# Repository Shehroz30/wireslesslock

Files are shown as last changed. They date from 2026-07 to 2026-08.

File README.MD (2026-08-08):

# Wireless bike lock

An ESP32-S3 hosts a web page over WiFi; the Open control energizes a latching solenoid in a
padlock body. The page also reports accelerometer and GPS readings.

The design covers two parts: the control PCB and the padlock. The rest is an existing bike
lock frame.

## How it works

An ESP32-S3 hosts a web page over WiFi; the Open control energizes a latching solenoid in a
padlock body. The page also reports accelerometer and GPS readings.

Interconnect sheet (parts, wiring diagram, wire schedule, open items):

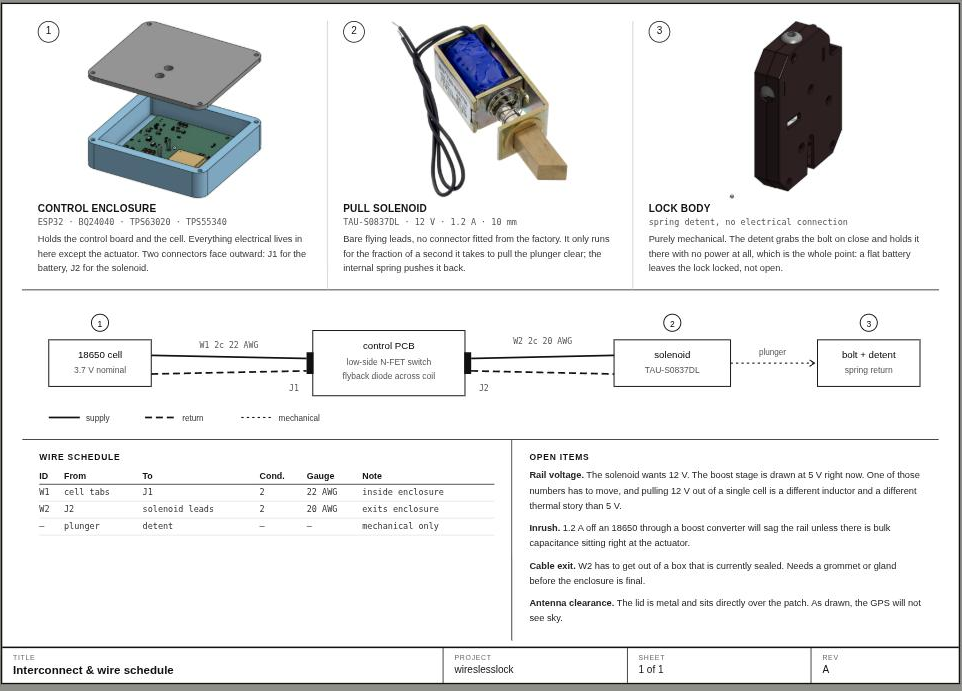
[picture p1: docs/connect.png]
Interconnect & wire schedule


Source (styled, printable): [connect.html](connect.html)

Mechanical design (enclosure and padlock body) is in Onshape:
<https://cad.onshape.com/documents/6c2c18833c9d8444570c43c7/w/6a4bb112d0b0db7159f785b0/e/d206a90808809049c3ae2997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>

PCB in enclosure:
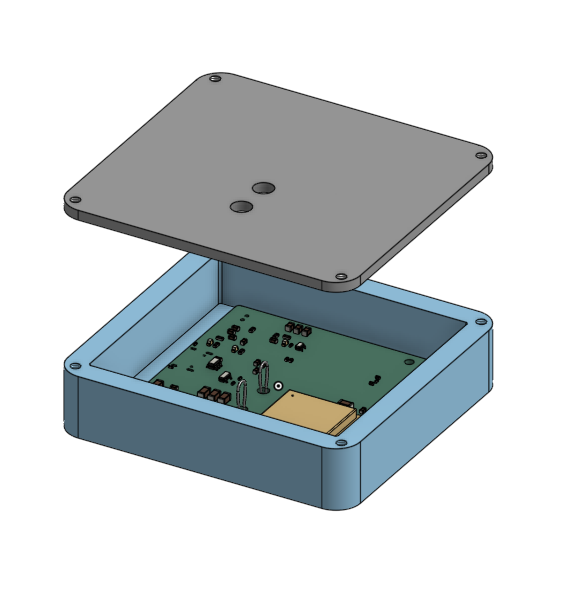
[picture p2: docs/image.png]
PCB in enclosure


Padlock with latching solenoid:
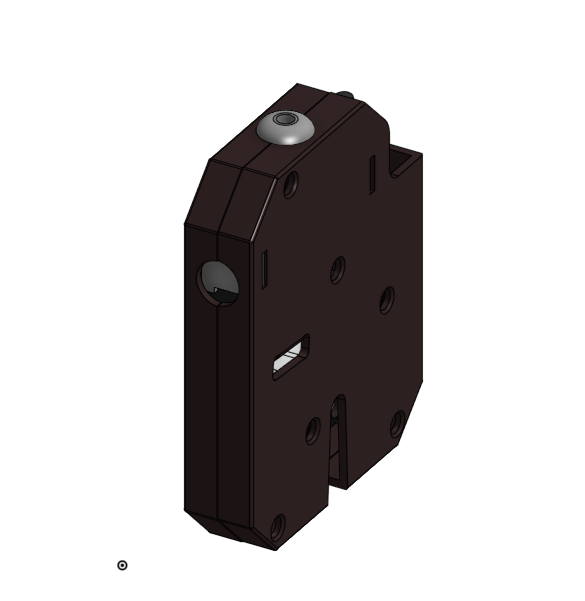
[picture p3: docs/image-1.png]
padlock


## Board specification

| | |
|---|---|
| Dimensions | 50 × 50 mm |
| Stackup | 4 layer (F.Cu / In1.Cu / In2.Cu / B.Cu), 1.6 mm |
| MCU | ESP32-S3-WROOM-1 (WiFi + BLE) |
| Power in | USB-C 5 V, single-cell Li-ion via JST-PH |
| Rails | 3.3 V system (buck-boost), 12 V solenoid (boost) |
| Sensors | LIS2DH12 accelerometer (SPI), SIM68M GNSS + SMD antenna (UART) |
| EDA | KiCad 10.0 |
| Placements | 67 across 44 BOM lines |

## Circuit description

### Power tree

```
USB-C (J1, 5V) ──> U1 BQ24040 ──> Li-ion cell (J2)
                   charge mgmt         │
                                       ├──> U3 TPS63020 buck-boost ──> +3.3V  (MCU, GPS, accel)
                                       │                                 │
                                       └── R7 10k pullup -> U3 EN        └──> U4 TPS55340 boost ──> +12V (solenoid)
```

`U1` (BQ24040) takes 5 V from USB-C and charges the cell. `R1` (560 Ω on ISET) sets the
fast-charge current; `D1`/`D2` are its status outputs. `R2`/`R3` are the 5.1 k CC pulldowns
that make a USB-C source supply 5 V, and `U2` (USBLC6-2SC6) clamps ESD on D+/D−.

The 3.3 V rail comes from `U3` (TPS63020), a buck-boost. A Li-ion cell sags from 4.2 V past
3.3 V as it discharges, so a buck-only regulator would brown out the ESP32 before the cell
was empty. Output is set by `R9` (1 M) / `R10` (180 k) around the 0.5 V reference → 3.28 V.
Inductor is `L2` (2.2 µH).

`U4` (TPS55340) boosts 3.3 V to 12 V through `L1` (10 µH) and `D3`, set by `R12` (86.6 k) /
`R13` (10 k) around the 1.229 V reference → ≈11.9 V. It is a separate rail so solenoid inrush
draws from the bulk caps (`C12`/`C14`/`C16`) rather than the MCU supply.

### Solenoid drive

`CTRL_P` (GPIO40) → `R18` (220 Ω gate series) → `Q1` (AO3400A, low-side N-ch FET). `R17`
(10 k) pulls the gate down so the coil is off through boot and reset. `D4` (S1M) is the
flyback diode across the coil. The coil connects to `TP1` (+12 V) and `TP2` (Q1 drain).

There is no hold-current limiting in hardware. The firmware caps coil energization time
instead (`MAX_OPEN_MS`, 5 s). Any other code driving `CTRL_P` must enforce the same limit.

### GPS

`U6` (SIM68M) streams NMEA at 9600 baud on the primary UART. `U8` (GPS1003) is the SMD
antenna, fed through a pi matching network: shunt `C22`, series `R19` (0 Ω), shunt `L4`
(18 nH). The 0 Ω / 0402 placeholders allow the match to be tuned after measurement.

## Pin map (U5, ESP32-S3-WROOM-1)

| Net | GPIO | Connects to |
|---|---|---|
| `CTRL_P` | 40 | Q1 gate (solenoid) via R18 |
| `LI_CS` | 10 | LIS2DH12 chip select |
| `SPI_MOSI` | 11 | LIS2DH12 SDI |
| `SPI_SCK` | 12 | LIS2DH12 SPC |
| `SPI_MISO` | 13 | LIS2DH12 SDO |
| `UART1_RX` | 17 | SIM68M TXD0, primary NMEA out |
| `UART1_TX` | 18 | SIM68M RXD0 |
| `UART0_RX` / `UART0_TX` | 6 / 7 | SIM68M secondary/debug UART |
| `BOOT` | 0 | SW3 tactile |
| `RST` | EN | SW2 tactile (R16 10 k pullup) |
| `TM` | — | Q2 → status LED D5; unused by the current firmware |

The accelerometer runs SPI mode 3 at 1 MHz. Its INT1/INT2 pins are not connected, so motion
detection is by polling.

## Firmware

The sketch is `firmware/wireslesslock_controller/wireslesslock_controller.ino`. It joins a
WiFi network, serves a page on port 80, and polls `/data` once a second for accelerometer and
GPS values. There is no cloud service or backend; the lock is reachable only on the local
network.

| Route | Method | Function |
|---|---|---|
| `/` | GET | Control page |
| `/data` | GET | JSON: `locked`, `accel.x/y/z` (g), `gps.fix/sats/lat/lon` |
| `/open` | POST | Energize solenoid (auto-releases after 5 s) |
| `/close` | POST | De-energize |

### Flashing

1. Arduino IDE → Boards Manager → install the esp32 package.
2. Library Manager → install TinyGPSPlus (Mikal Hart). The remaining dependencies are part of
   the ESP32 core.
3. Set `WIFI_SSID` / `WIFI_PASS` at the top of the sketch.
4. Connect over USB, select the board and port under Tools, and upload.

If upload stalls at `Connecting...`: hold BOOT (SW3), tap RESET (SW2), release BOOT. After
"Done uploading" the sketch is running; the serial monitor at 115200 baud prints the assigned
IP address.

## Fabrication

`gerbers.zip` is the fab package: 4 layer, 1.6 mm, 50 × 50 mm.

For assembly, `production/` holds `bom.csv`, `positions.csv`, `designators.csv`, and
`netlist.ipc`. These are generated by the KiCad Fabrication Toolkit plugin (settings in
`fabrication-toolkit-options.json`); regenerate them with the plugin rather than editing the
CSVs directly.

All parts are LCSC/JLCPCB-orderable except the solenoid and the battery, which are selected to
fit the padlock body.

## Bill of materials

67 placements, 44 lines. Machine-readable copy with purchase links: [BOM.csv](BOM.csv).
`production/bom.csv` is the plugin-generated file and is the reference for designators and
values; the table below adds the function of each part.

| Designator | Qty | Value | Footprint | Function | LCSC |
|---|---|---|---|---|---|
| `C1, C2` | 2 | 1uf | 0603 | USB VBUS / charger input bulk decoupling (U1 BQ24040 IN, OUT) | [C15849](https://www.lcsc.com/search?q=C15849) |
| `C10` | 1 | 100nF | 0402 | ESP32-S3 (U5) supply decoupling | [C1525](https://www.lcsc.com/search?q=C1525) |
| `C11, C19, C21, C7` | 4 | 0.1uF | 0603 | General IC decoupling (U4 VIN/VCC, GPS, accel) | [C14663](https://www.lcsc.com/search?q=C14663) |
| `C12, C14, C16, C5` | 4 | 4.7uF | 1206 | 12V solenoid rail bulk output caps (U4 boost output) | [C29823](https://www.lcsc.com/search?q=C29823) |
| `C13, C15, C17` | 3 | 22uf | 0805 | 3.3V rail bulk output caps (U3 buck-boost output) | [C45783](https://www.lcsc.com/search?q=C45783) |
| `C18, C26, C27, C3, C8` | 5 | 100nF | 0603 | Local HF decoupling, 3.3V rail | [C14663](https://www.lcsc.com/search?q=C14663) |
| `C20` | 1 | 22uF | 1206 | 3.3V bulk reservoir for RF/GPS current bursts | [C12891](https://www.lcsc.com/search?q=C12891) |
| `C22, R19` | 2 | 0 | 0402 | GPS antenna pi-match: shunt cap + series 0R (U8 -> U6 GNSS_ANT) | [C1952](https://www.lcsc.com/search?q=C1952) |
| `C23` | 1 | 4.7uF | 0402 | 3.3V decoupling, SIM68M GPS module (U6) | [C23733](https://www.lcsc.com/search?q=C23733) |
| `C28, C4, C6` | 3 | 10uF | 0603 | Mid-value decoupling, battery and 3.3V rails | [C19702](https://www.lcsc.com/search?q=C19702) |
| `C9` | 1 | 0.047uF | 0603 | TPS55340 (U4) soft-start cap on SS pin | [C1622](https://www.lcsc.com/search?q=C1622) |
| `D1, D2, D5` | 3 | LED | 0603 | Status LEDs: D1/D2 = BQ24040 CHG/PGOOD, D5 = MCU-driven (via Q2) | [C2290](https://www.lcsc.com/search?q=C2290) |
| `D3` | 1 | D_Schottky | SMA_L4.3-W2.7-LS5.1-RD | Boost rectifier for U4 (SW node -> +12V) | [C8678](https://www.lcsc.com/search?q=C8678) |
| `D4` | 1 | S1M | SMA_L4.3-W2.7-LS5.1-RD | Flyback/freewheel diode across the solenoid coil | [C51898151](https://www.lcsc.com/search?q=C51898151) |
| `J1` | 1 | MC-311D | USB-C-SMD_MC-311D | USB-C receptacle: 5V charge input + native USB D+/D- | [C136423](https://www.lcsc.com/search?q=C136423) |
| `J2` | 1 | BATTERY | CONN-TH_S2B-PH-K-S-GW | JST-PH 2-pin Li-ion battery connector | [C157932](https://www.lcsc.com/search?q=C157932) |
| `L1` | 1 | 10uH | IND-SMD_L7.2-W6.6_GPSR07X0 | 10uH boost inductor for U4 (+3.3V -> +12V) | [C5189958](https://www.lcsc.com/search?q=C5189958) |
| `L2` | 1 | 2.2uH | L1008 | 2.2uH buck-boost inductor for U3 (TPS63020 L1/L2 pins) | [C86092](https://www.lcsc.com/search?q=C86092) |
| `L4` | 1 | 18nH | 0402 | 18nH shunt inductor, GPS antenna matching network | [C86060](https://www.lcsc.com/search?q=C86060) |
| `Q1` | 1 | AO3400A | SOT-23 | N-ch FET, low-side solenoid driver (gate = CTRL_P / GPIO40) | [C20917](https://www.lcsc.com/search?q=C20917) |
| `Q2` | 1 | DTC143Z | SOT-323_SC-70 | Digital NPN (built-in bias) driving status LED D5 from net TM | [C53066](https://www.lcsc.com/search?q=C53066) |
| `R1` | 1 | 560 | 0603 | BQ24040 ISET: sets fast-charge current | [C23204](https://www.lcsc.com/search?q=C23204) |
| `R10` | 1 | 180k | 0603 | U3 (TPS63020) feedback divider, bottom leg -> 3.3V out | [C22827](https://www.lcsc.com/search?q=C22827) |
| `R11` | 1 | 75k | 0603 | U4 (TPS55340) FREQ pin: switching frequency set | [C23242](https://www.lcsc.com/search?q=C23242) |
| `R12` | 1 | 86.6K | 0603 | U4 feedback divider, top leg from +12V | [C23121](https://www.lcsc.com/search?q=C23121) |
| `R13, R16, R7` | 3 | 10k | 0603 | R13 = U4 FB bottom leg (12V), R16 = RST pullup, R7 = U3 EN pullup | [C25804](https://www.lcsc.com/search?q=C25804) |
| `R17` | 1 | 10k | 0402 | Gate pulldown on CTRL_P (holds solenoid off during boot/reset) | [C60489](https://www.lcsc.com/search?q=C60489) |
| `R18` | 1 | 220 | 0402 | Gate series resistor for Q1 | [C25091](https://www.lcsc.com/search?q=C25091) |
| `R2, R3` | 2 | 5.1k | 0402 | USB-C CC1/CC2 5.1k pulldowns (advertise 5V sink) | [C25905](https://www.lcsc.com/search?q=C25905) |
| `R20` | 1 | 1k | 0402 | Series resistor for status LED D5 | [C11702](https://www.lcsc.com/search?q=C11702) |
| `R4, R5` | 2 | 1k | 0603 | Series resistors for charge-status LEDs D1/D2 | [C21190](https://www.lcsc.com/search?q=C21190) |
| `R8` | 1 | 2k | 0603 | U4 COMP network resistor (loop compensation) | [C22975](https://www.lcsc.com/search?q=C22975) |
| `R9` | 1 | 1M | 0603 | U3 feedback divider, top leg from 3.3V out | [C22935](https://www.lcsc.com/search?q=C22935) |
| `SW2, SW3` | 2 | TS-1088-AR02016 | SW-SMD_L3.9-W3.0-P4.45 | Tactile switches: SW2 = RESET (EN), SW3 = BOOT (IO0) | [C720477](https://www.lcsc.com/search?q=C720477) |
| `TP1` | 1 | VCC_SOL | TestPoint_Loop_D3.80mm_Drill2.8mm | Test point / solenoid output: +12V | — |
| `TP2` | 1 | GND_SOL | TestPoint_Loop_D3.80mm_Drill2.8mm | Test point / solenoid output: switched low side (Q1 drain) | — |
| `U1` | 1 | BQ24040DSQR | WSON-10_L2.0-W2.0-P0.40-BL-EP | Li-ion linear charge management IC (USB 5V -> battery) | [C81080](https://www.lcsc.com/search?q=C81080) |
| `U2` | 1 | USBLC6-2SC6 | SOT-23-6 | USB D+/D- ESD protection array | [C2827654](https://www.lcsc.com/search?q=C2827654) |
| `U3` | 1 | TPS63020DSJR | VSON-14_L4.0-W3.0-P0.50-BL-EP_TI_DSJ | Buck-boost converter: battery (2.5-5.5V) -> 3.3V system rail | [C15483](https://www.lcsc.com/search?q=C15483) |
| `U4` | 1 | TPS55340RTER | VQFN-16_L3.0-W3.0-P0.50-BL-EP1.7 | Boost converter: 3.3V -> 12V solenoid rail | [C169167](https://www.lcsc.com/search?q=C169167) |
| `U5` | 1 | ESP32-S3-WROOM-1 | ESP32-S3-WROOM-1 | Main MCU/radio: ESP32-S3, WiFi + BLE, hosts the control page | [C2913202](https://www.lcsc.com/search?q=C2913202) |
| `U6` | 1 | SIM68M | GPSM-SMD_18P-L10.1-W9.7-P1.10 | GNSS receiver module, NMEA out over UART at 9600 baud | [C2999762](https://www.lcsc.com/search?q=C2999762) |
| `U7` | 1 | LIS2DH12TR | LGA-12_L2.0-W2.0-P0.50-BL | 3-axis accelerometer (SPI) - tamper / motion detection | [C110926](https://www.lcsc.com/search?q=C110926) |
| `U8` | 1 | GPS1003 | ANT-SMD_L10.0-W3.0 | SMD GPS patch antenna, 1575.42 MHz | [C239243](https://www.lcsc.com/search?q=C239243) |

Not on the BOM, selected to fit the padlock:

| Item | Notes |
|---|---|
| Latching solenoid | Driven from TP1/TP2 at 12 V, low-side switched |
| Li-ion cell | Single cell, JST-PH 2-pin to J2 |

## Repository layout

```
wireslesslock.kicad_pro      project file
wireslesslock.kicad_sch      root schematic (MCU, GPS, accel, switches)
power.kicad_sch              "Power" sub-sheet (charging, both converters, USB-C)
wireslesslock.kicad_pcb      4-layer board layout
easyeda2kicad.*              project-local library: parts converted from LCSC/EasyEDA
                             (BQ24040, TPS63020, TPS55340, GPS antenna, WSON/VSON pkgs)
BOM.csv                      annotated BOM (this README's table)
production/                  generated fab outputs (plugin output, not source)
gerbers.zip                  fab package
firmware/                    ESP32-S3 Arduino sketch
3dfiles/                     STEP export + padlock mechanism snapshots from Onshape
docs/                        README images
archive/                     timestamped project backups
```

## Verifying changes

There is no build or test command. Changes are verified by opening the project in KiCad and
running ERC on the schematic and DRC on the board.

## License

[MIT](LICENSE).

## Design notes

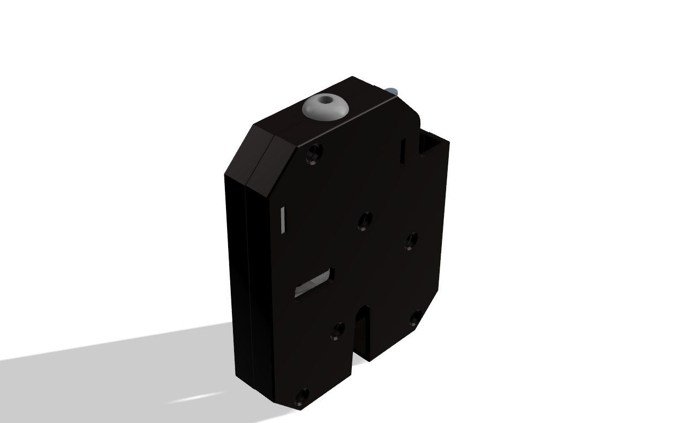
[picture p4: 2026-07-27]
3dfiles/solenoid-lock-combine-lock-1.snapshot.3/Screenshot (61).png

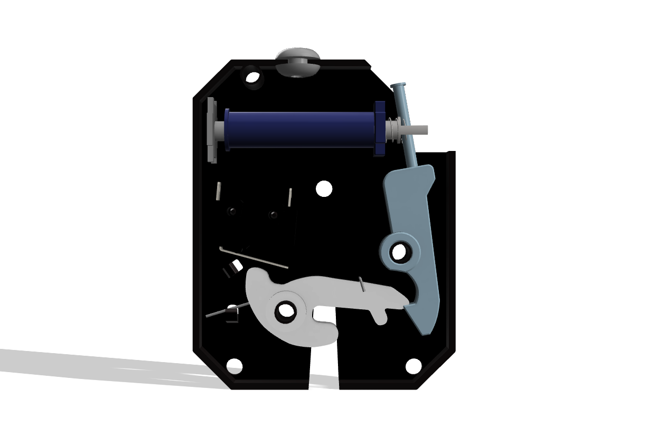
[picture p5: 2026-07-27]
3dfiles/solenoid-lock-combine-lock-1.snapshot.3/Screenshot (64).png

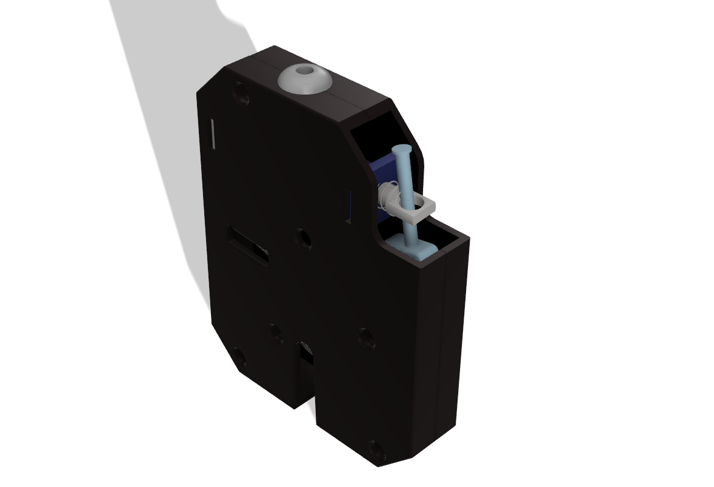
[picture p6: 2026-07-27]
3dfiles/solenoid-lock-combine-lock-1.snapshot.3/Screenshot (59).png

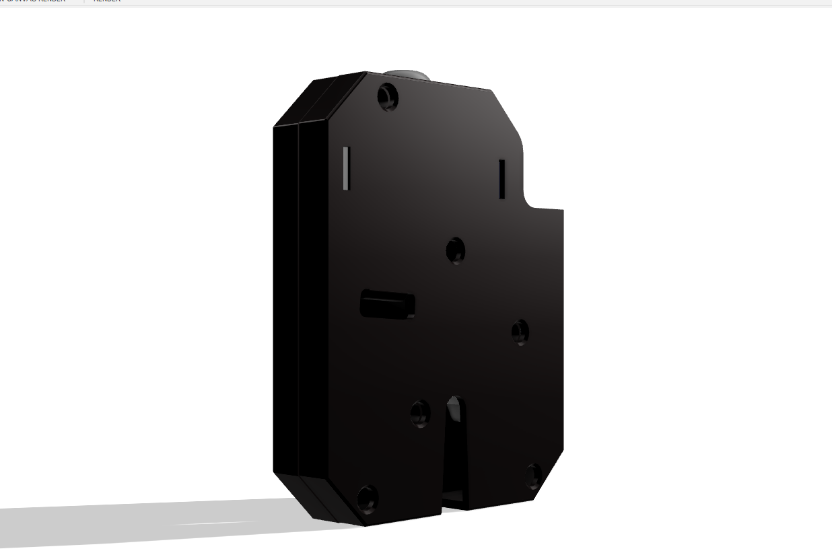
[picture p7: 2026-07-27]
3dfiles/solenoid-lock-combine-lock-1.snapshot.3/Screenshot (57).png

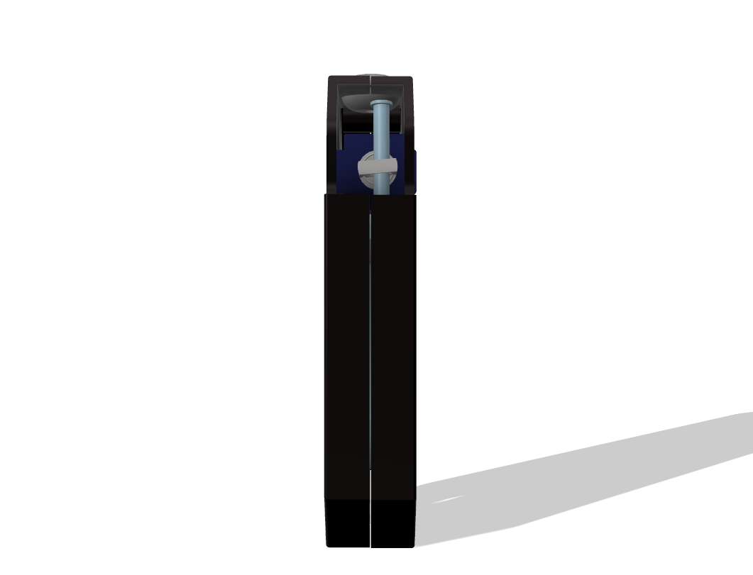
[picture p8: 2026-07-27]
3dfiles/solenoid-lock-combine-lock-1.snapshot.3/Screenshot (63).png

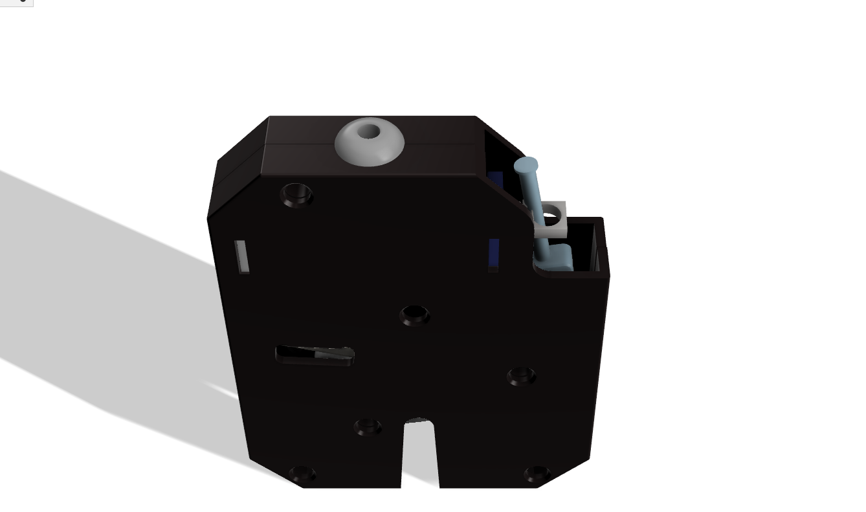
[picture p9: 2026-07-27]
3dfiles/solenoid-lock-combine-lock-1.snapshot.3/Screenshot (60).png

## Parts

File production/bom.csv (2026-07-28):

Designator | Footprint | Quantity | Value | LCSC Part #
C1, C2 | 0603 | 2 | 1uf
C10 | 0402 | 1 | 100nF
C11, C19, C21, C7 | 0603 | 4 | 0.1uF
C12, C14, C16, C5 | 1206 | 4 | 4.7uF
C13, C15, C17 | 0805 | 3 | 22uf
C18, C26, C27, C3, C8 | 0603 | 5 | 100nF
C20 | 1206 | 1 | 22uF
C22, R19 | 0402 | 2 | 0
C23 | 0402 | 1 | 4.7uF
C28, C4, C6 | 0603 | 3 | 10uF
C9 | 0603 | 1 | 0.047uF
D1, D2, D5 | 0603 | 3 | LED
D3 | SMA_L4.3-W2.7-LS5.1-RD | 1 | D_Schottky
D4 | SMA_L4.3-W2.7-LS5.1-RD | 1 | S1M
J1 | USB-C-SMD_MC-311D | 1 | MC-311D | C136423
J2 | CONN-TH_S2B-PH-K-S-GW | 1 | BATTERY
L1 | IND-SMD_L7.2-W6.6_GPSR07X0 | 1 | 10uH
L2 | L1008 | 1 | 2.2uH
L4 | 0402 | 1 | 18nH
Q1 | SOT-23 | 1 | AO3400A
Q2 | SOT-323_SC-70 | 1 | DTC143Z
R1 | 0603 | 1 | 560
R10 | 0603 | 1 | 180k
R11 | 0603 | 1 | 75k
R12 | 0603 | 1 | 86.6K
R13, R16, R7 | 0603 | 3 | 10k
R17 | 0402 | 1 | 10k
R18 | 0402 | 1 | 220
R2, R3 | 0402 | 2 | 5.1k
R20 | 0402 | 1 | 1k
R4, R5 | 0603 | 2 | 1k
R8 | 0603 | 1 | 2k
R9 | 0603 | 1 | 1M
SW2, SW3 | SW-SMD_L3.9-W3.0-P4.45 | 2 | TS-1088-AR02016 | C720477
TP1 | TestPoint_Loop_D3.80mm_Drill2.8mm | 1 | VCC_SOL
TP2 | TestPoint_Loop_D3.80mm_Drill2.8mm | 1 | GND_SOL
U1 | WSON-10_L2.0-W2.0-P0.40-BL-EP | 1 | BQ24040DSQR | C81080
U2 | SOT-23-6 | 1 | USBLC6-2SC6
U3 | VSON-14_L4.0-W3.0-P0.50-BL-EP_TI_DSJ | 1 | TPS63020DSJR | C15483
U4 | VQFN-16_L3.0-W3.0-P0.50-BL-EP1.7 | 1 | TPS55340RTER | C169167
U5 | ESP32-S3-WROOM-1 | 1 | ESP32-S3-WROOM-1
U6 | GPSM-SMD_18P-L10.1-W9.7-P1.10 | 1 | SIM68M | C2999762
U7 | LGA-12_L2.0-W2.0-P0.50-BL | 1 | LIS2DH12TR | C110926
U8 | ANT-SMD_L10.0-W3.0 | 1 | GPS1003 | C239243

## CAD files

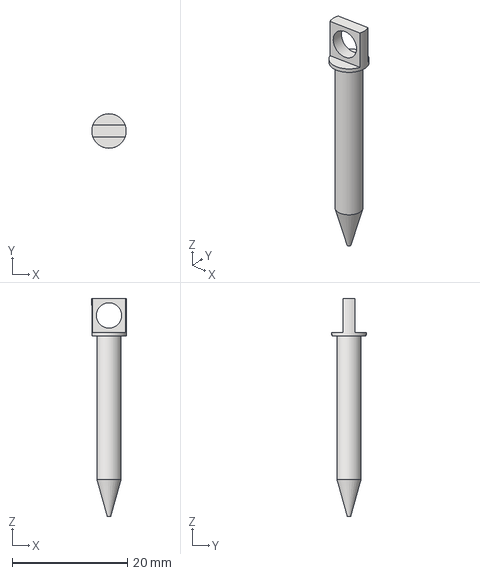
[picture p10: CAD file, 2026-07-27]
3dfiles/solenoid-lock-combine-lock-1.snapshot.3/#2 part 6 pin .step
6.00 x 6.00 x 37.9 mm

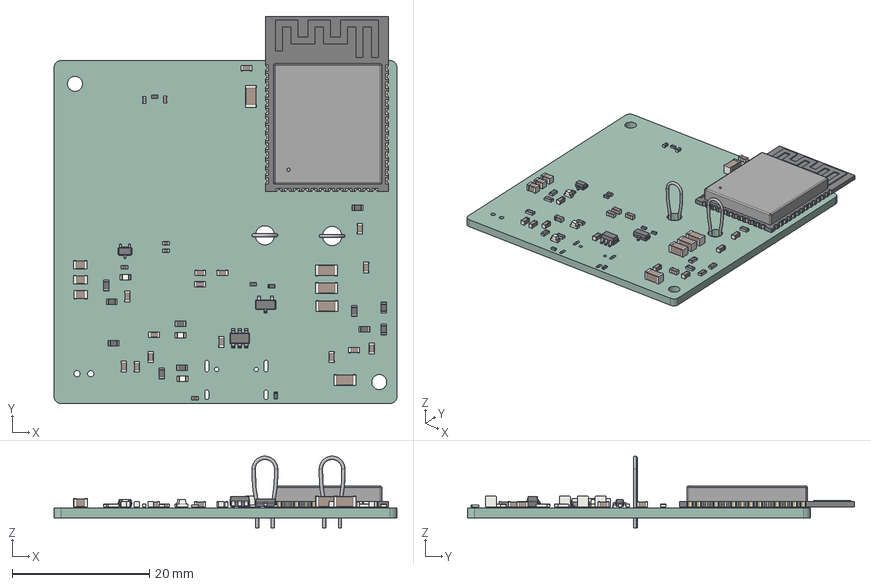
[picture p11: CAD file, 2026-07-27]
3dfiles/wireslesslock.step
50.0 x 56.4 x 10.4 mm
C_1206_3216Metric x 5
R_0402_1005Metric x 6
C_0603_1608Metric x 15
R_0603_1608Metric x 11
C_0402_1005Metric x 3
C_0805_2012Metric x 3
LED_0603_1608Metric x 3
SOT-323_SC-70
TestPoint_Loop_D3.80mm_Drill2.8mm x 2
SOT-23-6
L_0402_1005Metric
SOT-23
ESP32-S3-WROOM-1
wireslesslock_PCB

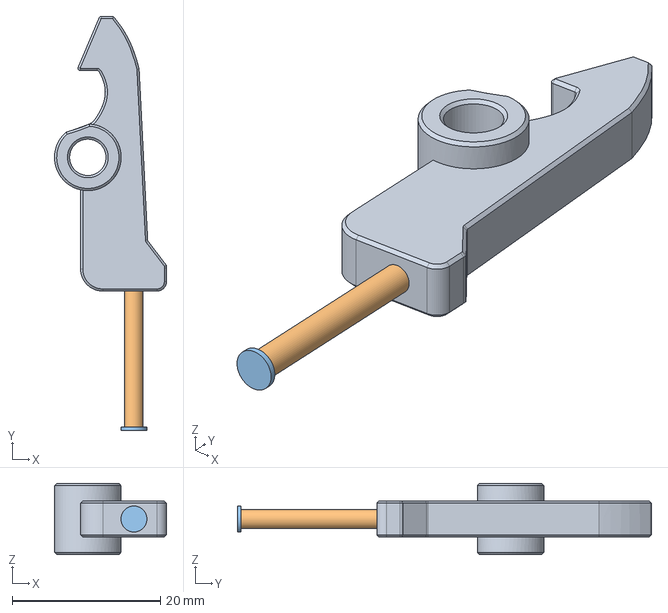
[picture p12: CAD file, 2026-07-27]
3dfiles/solenoid-lock-combine-lock-1.snapshot.3/#2 part 2 long hook .step
15.1 x 55.8 x 9.60 mm

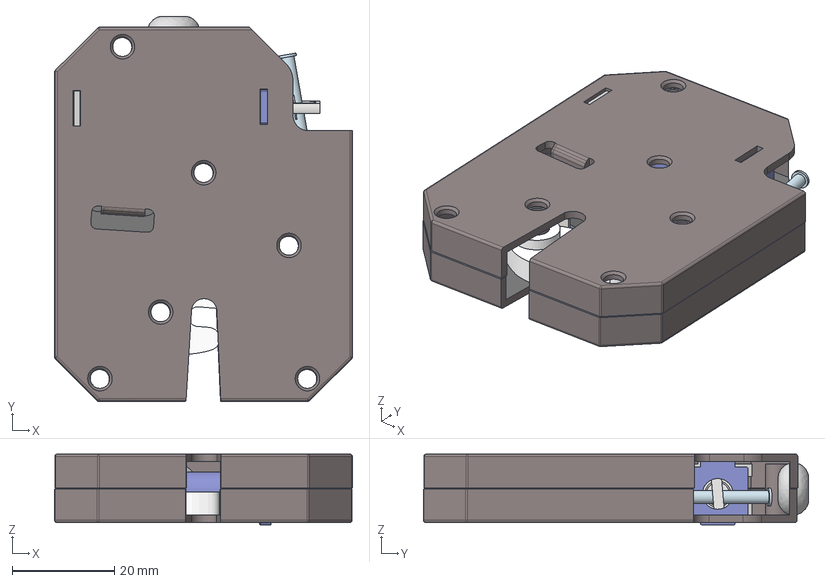
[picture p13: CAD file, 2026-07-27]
3dfiles/solenoid-lock-combine-lock-1.snapshot.3/#1 v1.step
58.2 x 75.2 x 13.9 mm
Bottom
Top

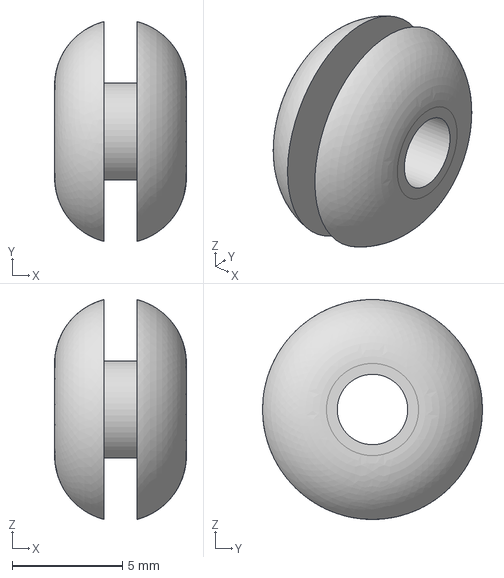
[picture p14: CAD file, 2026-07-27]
3dfiles/solenoid-lock-combine-lock-1.snapshot.3/#1 part2 .step
6.00 x 10.00 x 10.0 mm

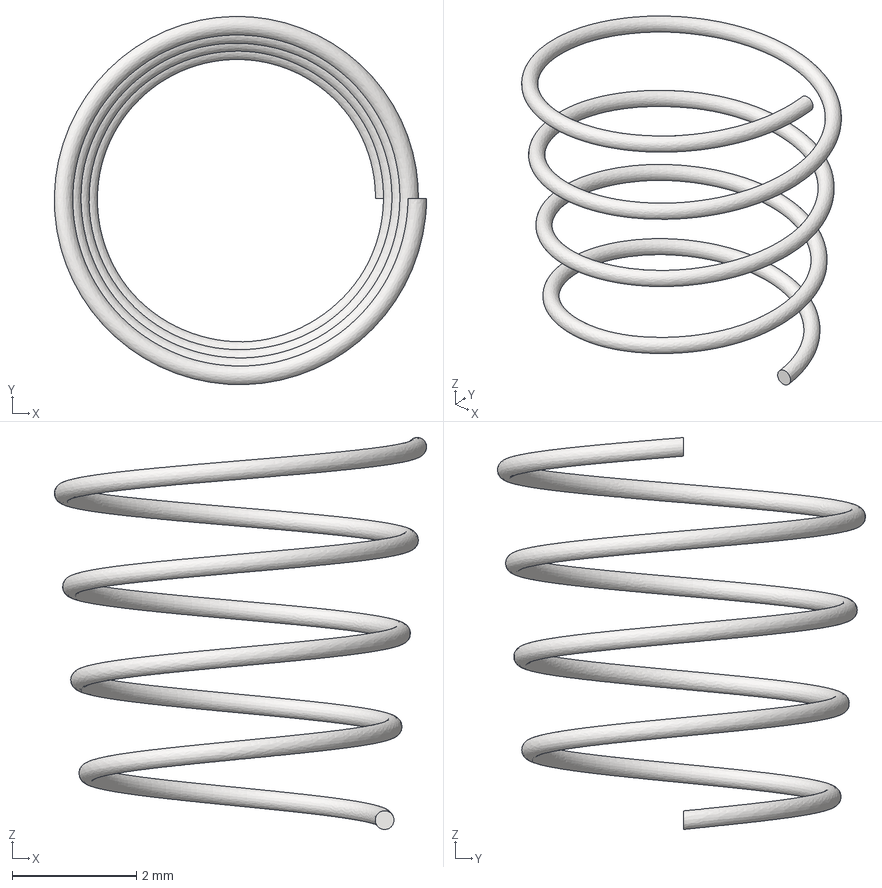
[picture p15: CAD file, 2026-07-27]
3dfiles/solenoid-lock-combine-lock-1.snapshot.3/#2 part spring .step
5.98 x 5.92 x 6.30 mm

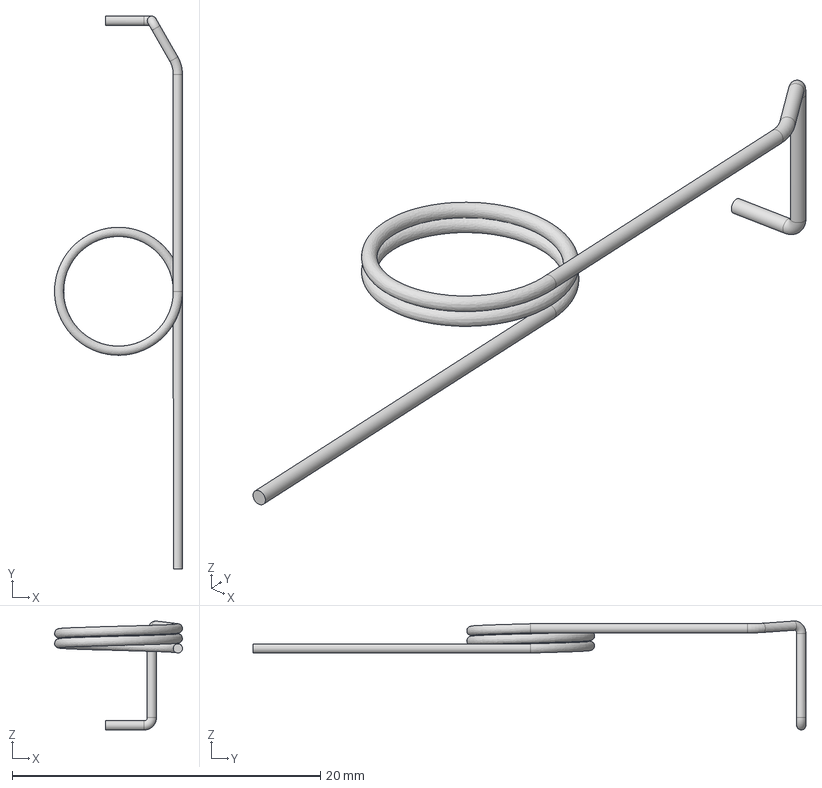
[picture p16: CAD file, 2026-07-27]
3dfiles/solenoid-lock-combine-lock-1.snapshot.3/#2 part 8 torsion spring .step
8.30 x 35.8 x 7.07 mm

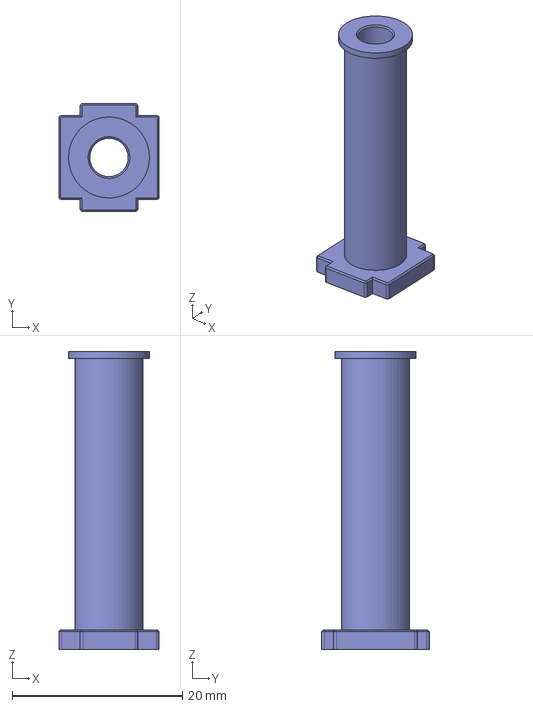
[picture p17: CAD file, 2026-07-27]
3dfiles/solenoid-lock-combine-lock-1.snapshot.3/#2 part long coil .step
11.8 x 12.7 x 35.0 mm

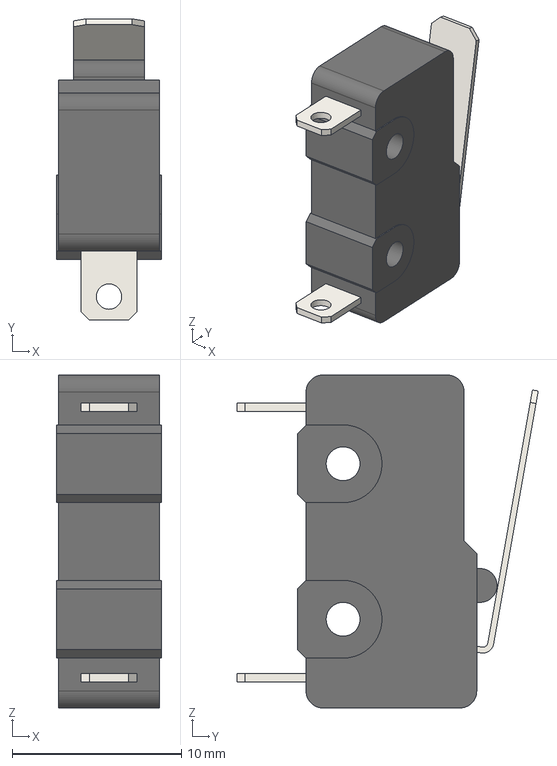
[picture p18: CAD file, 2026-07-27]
3dfiles/solenoid-lock-combine-lock-1.snapshot.3/#2 part 4 switch .step
6.20 x 17.8 x 19.7 mm

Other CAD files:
3dfiles/solenoid-lock-combine-lock-1.snapshot.3/#2 part long coil.step

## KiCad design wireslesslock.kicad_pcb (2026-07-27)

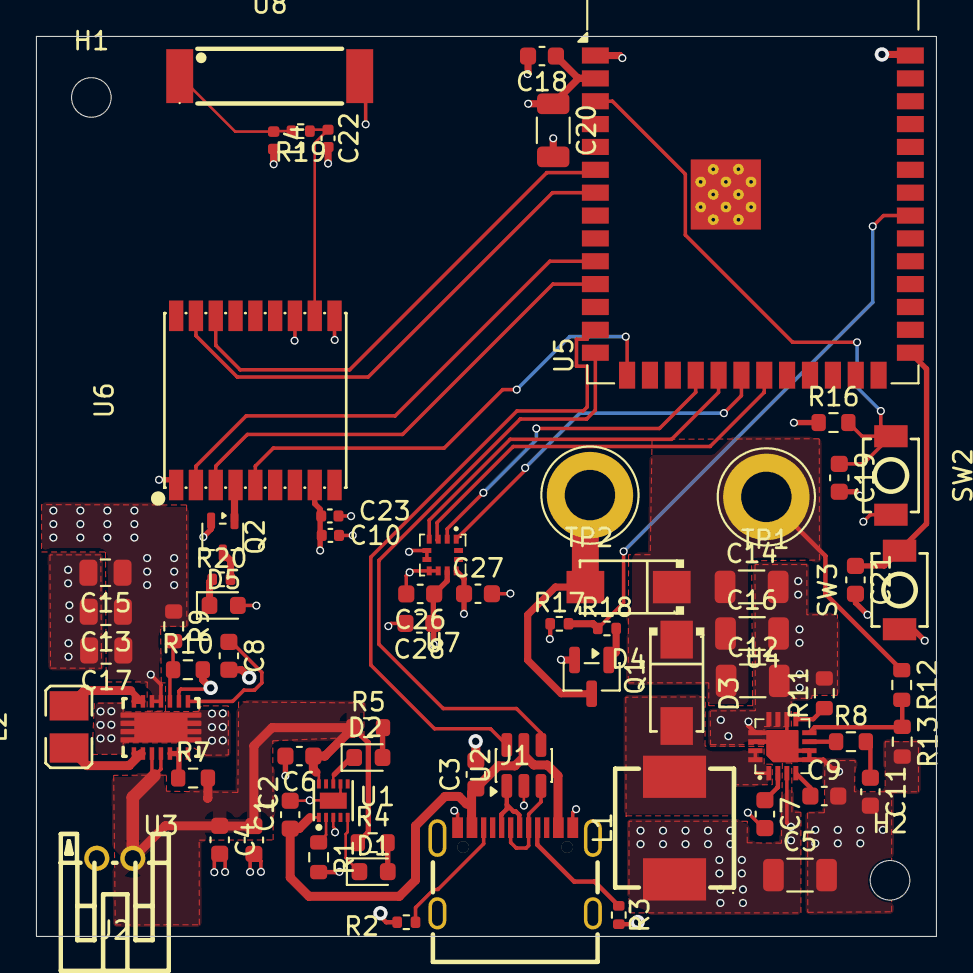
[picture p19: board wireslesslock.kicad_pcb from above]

Board: 4 copper layers, 50.0 x 50.0 mm, 69 parts (0 on the bottom side), 47 nets.

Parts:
C1, C2: 1uf; C_0603_1608Metric
C3, C18, C26, C27: 100nF; C_0603_1608Metric
C4, C6: 10uf; C_0603_1608Metric
C5, C12, C14, C16: 4.7uF; C_1206_3216Metric
C7, C11, C19, C21: 0.1uF; C_0603_1608Metric
C8: 100nf; C_0603_1608Metric
C9: 0.047uF; C_0603_1608Metric
C10: 100nF; C_0402_1005Metric
C13, C15, C17: 22uf; C_0805_2012Metric
C20: 22uF; C_1206_3216Metric
C22: 0; C_0402_1005Metric
C23: 4.7uF; C_0402_1005Metric
C28: 10uF; C_0603_1608Metric
D1, D2, D5: LED; LED_0603_1608Metric
D3: D_Schottky; SMA_L4.3-W2.7-LS5.1-RD
D4: S1M; SMA_L4.3-W2.7-LS5.1-RD
H1, H2: MountingHole; MountingHole_2.2mm_M2
J1: MC-311D; USB-C-SMD_MC-311D
J2: BATTERY; CONN-TH_S2B-PH-K-S-GW
L1: 10uH; IND-SMD_L7.2-W6.6_GPSR07X0
L2: 2.2uH; L1008
L4: 18nH; L_0402_1005Metric
Q1: AO3400A; SOT-23
Q2: DTC143Z; SOT-323_SC-70
R1: 560; R_0603_1608Metric
R2, R3: 5.1k; R_0402_1005Metric
R4, R5: 1k; R_0603_1608Metric
R7, R13, R16: 10k; R_0603_1608Metric
R8: 2k; R_0603_1608Metric
R9: 1M; R_0603_1608Metric
R10: 180k; R_0603_1608Metric
R11: 75k; R_0603_1608Metric
R12: 86.6K; R_0603_1608Metric
R17: 10k; R_0402_1005Metric
R18: 220; R_0402_1005Metric
R19: 0; R_0402_1005Metric
R20: 1k; R_0402_1005Metric
SW2, SW3: TS-1088-AR02016; SW-SMD_L3.9-W3.0-P4.45
TP1: VCC_SOL; TestPoint_Loop_D3.80mm_Drill2.8mm
TP2: GND_SOL; TestPoint_Loop_D3.80mm_Drill2.8mm
U1: BQ24040DSQR; WSON-10_L2.0-W2.0-P0.40-BL-EP
U2: USBLC6-2SC6; SOT-23-6
U3: TPS63020DSJR; VSON-14_L4.0-W3.0-P0.50-BL-EP_TI_DSJ
U4: TPS55340RTER; VQFN-16_L3.0-W3.0-P0.50-BL-EP1.7
U5: ESP32-S3-WROOM-1
U6: SIM68M; GPSM-SMD_18P-L10.1-W9.7-P1.10
U7: LIS2DH12TR; LGA-12_L2.0-W2.0-P0.50-BL
U8: GPS1003; ANT-SMD_L10.0-W3.0

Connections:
+3.3V: C5.1, C10.1, C13.1, C15.1, C17.1, C18.1, C20.1, C23.1, C26.1, C27.1, C28.1, D5.2 (A), L1.1, R9.1, R16.1, U3.4 (VOUT), U3.5 (VOUT), U4.3 (EN), U5.2 (3V3), U6.8 (VCC), U7.9 (VDD), U7.10 (VDD_IO)
+5V: C1.1, C3.1, J1.A4-B9 (VBUS), J1.B4-A9 (VBUS), U1.1 (IN), U2.5 (VBUS)
+12V: C12.1, C14.1, C16.1, D3.1 (K), D4.1 (K), R12.1, TP1.1 (1_1)
/wireslesslock/BOOT: C21.1, SW3.2, U5.27 (IO0)
/wireslesslock/CTRL_P: R17.2, R18.1, U5.33 (IO40)
/wireslesslock/LI_CS: U5.18 (IO10), U7.2 (CS)
/wireslesslock/RST: C19.1, R16.2, SW2.1, U5.3 (EN)
/wireslesslock/SIM_INT: U5.15 (IO3), U6.5 (EXTINT)
/wireslesslock/SPI_MISO: U5.21 (IO13), U7.3 (SDO/SA0)
/wireslesslock/SPI_MOSI: U5.19 (IO11), U7.4 (SDA/SDI/SDO)
/wireslesslock/SPI_SCK: U5.20 (IO12), U7.1 (SCL/SPC)
/wireslesslock/TM: Q2.1 (B), U6.4 (TIMEMARK)
/wireslesslock/UART0_RX: U5.6 (IO6), U6.16 (TXD1/SDA)
/wireslesslock/UART0_TX: U5.7 (IO7), U6.17 (RXD1/SCL)
/wireslesslock/UART1_RX: U5.10 (IO17), U6.2 (TXD0)
/wireslesslock/UART1_TX: U5.11 (IO18), U6.3 (RXD0)
D+: U2.4 (I/O2), U5.14 (USB_D+)
D-: U2.6 (I/O1), U5.13 (USB_D-)
GND: C1.2, C2.2, C3.2, C4.2, C5.2, C6.2, C7.2, C8.2, C9.2, C10.2, C11.2, C12.2, C13.2, C14.2, C15.2, C16.2, C17.2, C18.2, C19.2, C20.2, C21.2, C22.2, C23.2, C26.2, C27.2, C28.2, J1.A1-B12 (GND), J1.B1-A12 (GND), J2.1, L4.2, Q1.2 (S), Q2.2 (E), R1.2, R2.2, R3.2, R10.2, R11.2, R13.2, R17.1, SW2.2, SW3.1, U1.3 (VSS), U1.7 (ISET2), U1.11 (EP), U2.2 (GND), U3.2 (GND), U3.15 (PGND), U4.5 (SYNC), U4.6 (AGND), U4.10 (NC), U4.11 (PGND), U4.12 (PGND), U4.13 (PGND), U4.14 (NC), U4.17 (EP), U5.1 (GND), U5.40 (GND), U5.41 (GND), U6.1 (GND), U6.10 (GND), U6.12 (GND), U7.5 (RES), U7.6 (GND), U7.7 (GND), U7.8 (GND), U8.2
unnamed: C11.1, R8.2
unnamed: D1.2 (A), R4.2
unnamed: D1.1 (K), U1.5 (~PG)
unnamed: D2.2 (A), R5.2
unnamed: D2.1 (K), U1.8 (~CHG)
unnamed: D3.2 (A), L1.2, U4.1 (SW), U4.15 (SW), U4.16 (SW)
unnamed: D4.2 (A), Q1.3 (D), TP2.1 (1_1)
unnamed: D5.1 (K), R20.1
unnamed: J1.A7 (DN1), J1.B7 (DN2), U2.1 (I/O1)
unnamed: J1.A6 (DP1), J1.B6 (DP2), U2.3 (I/O2)
unnamed: J1.A8 (SBU1), R3.1
unnamed: J1.B8 (SBU2), R2.1
unnamed: C2.1, C4.1, C6.1, J2.2, R4.1, R5.1, R7.2, U1.10 (OUT), U3.10 (VIN), U3.11 (VIN)
unnamed: L2.1, U3.8 (L1), U3.9 (L1)
unnamed: L2.2, U3.6 (L2), U3.7 (L2)
unnamed: L4.1, R19.2, U8.1
unnamed: Q1.1 (G), R18.2
unnamed: Q2.3 (C), R20.2
unnamed: R1.1, U1.2 (ISET)
unnamed: R7.1, U3.12 (EN), U3.13 (PS/SYNC)
unnamed: R9.2, R10.1, U3.3 (FB)
unnamed: C8.1, U3.1 (VINA)
unnamed: R8.1, U4.7 (COMP)
unnamed: R12.2, R13.1, U4.8 (FB)
unnamed: R11.1, U4.9 (FREQ)
unnamed: C9.1, U4.4 (SS)
unnamed: C7.1, U4.2 (VIN)
unnamed: C22.1, R19.1, U6.11 (GNSS_ANT)

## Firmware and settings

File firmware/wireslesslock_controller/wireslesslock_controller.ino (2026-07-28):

// wireslesslock controller (ESP32-S3-WROOM-1)
// Hosts a local web page over WiFi to open/close the solenoid lock and
// shows live accelerometer + GPS readings (page polls /data every second,
// no cloud/backend involved).
//
// Pin map, derived from wireslesslock.kicad_sch (label -> nearest symbol pin):
//   CTRL_P (Q1 solenoid gate driver)      -> GPIO40
//   LIS2DH12 SPI: CS=GPIO10 SCK=GPIO12 MOSI=GPIO11 MISO=GPIO13
//   SIM68M GPS, primary NMEA UART (net UART1_RX/TX): RX=GPIO17 TX=GPIO18, 9600 baud
//
// Requires the "TinyGPSPlus" library (Library Manager, by Mikal Hart) for
// NMEA parsing; everything else is bundled with the ESP32 Arduino core.

#include <WiFi.h>
#include <WebServer.h>
#include <SPI.h>
#include <TinyGPSPlus.h>

// ---- fill in before flashing ----
const char *WIFI_SSID = "YOUR_WIFI";
const char *WIFI_PASS = "YOUR_PASSWORD";

// ---- pins ----
const int SOLENOID_PIN = 40; // CTRL_P
const int LIS_CS = 10, LIS_SCK = 12, LIS_MOSI = 11, LIS_MISO = 13;
const int GPS_RX = 17, GPS_TX = 18;

// ponytail: no PWM hold-current limiting in hardware, so a client that
// never calls /close would otherwise cook the coil; cap how long it can
// stay energized regardless of what the web page does.
const unsigned long MAX_OPEN_MS = 5000;

WebServer server(80);
TinyGPSPlus gps;
HardwareSerial gpsSerial(1);

bool solenoidOpen = false;
unsigned long openedAt = 0;
float accelX = 0, accelY = 0, accelZ = 0;

// ---------- LIS2DH12 accelerometer: minimal register-level SPI driver ----------
void lisWrite(uint8_t reg, uint8_t val) {
  SPI.beginTransaction(SPISettings(1000000, MSBFIRST, SPI_MODE3));
  digitalWrite(LIS_CS, LOW);
  SPI.transfer(reg & 0x3F); // write, no auto-increment
  SPI.transfer(val);
  digitalWrite(LIS_CS, HIGH);
  SPI.endTransaction();
}

void lisReadAccel() {
  SPI.beginTransaction(SPISettings(1000000, MSBFIRST, SPI_MODE3));
  digitalWrite(LIS_CS, LOW);
  SPI.transfer(0x28 | 0xC0); // OUT_X_L, read + auto-increment
  uint8_t b[6];
  for (int i = 0; i < 6; i++) b[i] = SPI.transfer(0x00);
  digitalWrite(LIS_CS, HIGH);
  SPI.endTransaction();

  int16_t x = (int16_t)((b[1] << 8) | b[0]) >> 4; // normal mode: 10 bits, left-justified
  int16_t y = (int16_t)((b[3] << 8) | b[2]) >> 4;
  int16_t z = (int16_t)((b[5] << 8) | b[4]) >> 4;
  const float SENS = 0.004f; // g/LSB, normal mode, +-2g range
  accelX = x * SENS;
  accelY = y * SENS;
  accelZ = z * SENS;
}

// ---------- solenoid ----------
void setSolenoid(bool open) {
  digitalWrite(SOLENOID_PIN, open ? HIGH : LOW);
  solenoidOpen = open;
  openedAt = open ? millis() : 0;
}

// ---------- web ----------
const char PAGE[] PROGMEM = R"HTML(
<!DOCTYPE html><html><head><meta name="viewport" content="width=device-width,initial-scale=1">
<title>wireslesslock</title>
<style>body{font-family:sans-serif;max-width:420px;margin:2rem auto;text-align:center}
button{font-size:1.2rem;padding:.75rem 1.5rem;margin:.5rem;border:0;border-radius:.5rem;color:#fff}
#open{background:#2e7d32}#close{background:#c62828}
table{margin:1rem auto;text-align:left}</style></head><body>
<h2>wireslesslock</h2>
<p>Status: <b id="status">-</b></p>
<button id="open" onclick="cmd('open')">Open</button>
<button id="close" onclick="cmd('close')">Close</button>
<table>
<tr><td>Accel (g)</td><td id="accel">-</td></tr>
<tr><td>GPS fix</td><td id="fix">-</td></tr>
<tr><td>Lat, Lon</td><td id="pos">-</td></tr>
</table>
<script>
function cmd(a){fetch('/'+a,{method:'POST'}).then(refresh);}
function refresh(){
  fetch('/data').then(r=>r.json()).then(d=>{
    document.getElementById('status').textContent = d.locked ? 'Locked' : 'OPEN';
    document.getElementById('accel').textContent = d.accel.x.toFixed(2)+', '+d.accel.y.toFixed(2)+', '+d.accel.z.toFixed(2);
    document.getElementById('fix').textContent = d.gps.fix ? ('yes ('+d.gps.sats+' sats)') : 'no';
    document.getElementById('pos').textContent = d.gps.fix ? d.gps.lat.toFixed(6)+', '+d.gps.lon.toFixed(6) : '-';
  });
}
setInterval(refresh, 1000);
refresh();
</script></body></html>
)HTML";

void handleRoot() { server.send_P(200, "text/html", PAGE); }

void handleData() {
  char buf[256];
  snprintf(buf, sizeof(buf),
    "{\"locked\":%s,\"accel\":{\"x\":%.3f,\"y\":%.3f,\"z\":%.3f},"
    "\"gps\":{\"fix\":%s,\"sats\":%d,\"lat\":%.6f,\"lon\":%.6f}}",
    solenoidOpen ? "false" : "true",
    accelX, accelY, accelZ,
    gps.location.isValid() ? "true" : "false",
    gps.satellites.isValid() ? gps.satellites.value() : 0,
    gps.location.isValid() ? gps.location.lat() : 0.0,
    gps.location.isValid() ? gps.location.lng() : 0.0);
  server.send(200, "application/json", buf);
}

void handleOpen()  { setSolenoid(true);  server.send(200, "text/plain", "ok"); }
void handleClose() { setSolenoid(false); server.send(200, "text/plain", "ok"); }

void setup() {
  Serial.begin(115200);

  pinMode(SOLENOID_PIN, OUTPUT);
  digitalWrite(SOLENOID_PIN, LOW); // locked by default

  pinMode(LIS_CS, OUTPUT);
  digitalWrite(LIS_CS, HIGH);
  SPI.begin(LIS_SCK, LIS_MISO, LIS_MOSI, LIS_CS);
  lisWrite(0x20, 0x27); // CTRL_REG1: 10Hz, X/Y/Z enabled, normal mode

  gpsSerial.begin(9600, SERIAL_8N1, GPS_RX, GPS_TX);

  WiFi.begin(WIFI_SSID, WIFI_PASS);
  while (WiFi.status() != WL_CONNECTED) delay(200);
  Serial.print("wireslesslock web page: http://");
  Serial.println(WiFi.localIP());

  server.on("/", handleRoot);
  server.on("/data", handleData);
  server.on("/open", HTTP_POST, handleOpen);
  server.on("/close", HTTP_POST, handleClose);
  server.begin();
}

void loop() {
  server.handleClient();

  while (gpsSerial.available()) gps.encode(gpsSerial.read());

  static unsigned long lastAccel = 0;
  if (millis() - lastAccel > 200) {
    lisReadAccel();
    lastAccel = millis();
  }

  if (solenoidOpen && millis() - openedAt > MAX_OPEN_MS) setSolenoid(false);
}

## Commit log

2026-07-28 added links
    [bom_purchase_links.csv]
2026-07-28 added gerber
2026-08-07 docs: expand README and add annotated BOM.csv
    Rewrite the README with the circuit detail that was only in the schematic:
    power tree and the feedback dividers setting each rail, solenoid drive and
    its lack of hardware hold-current limiting, GPS matching network, verified
    ESP32-S3 pin map, firmware routes, and fab/assembly steps.
    Add BOM.csv: production/bom_purchase_links.csv plus a Function column
    saying what each part does, mirrored into the README as a table.
    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
    [BOM.csv]
